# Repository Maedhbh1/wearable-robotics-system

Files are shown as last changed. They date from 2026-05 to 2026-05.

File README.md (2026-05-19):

# The Case for Misandry: A Networked Wearable Robotic Ecosystem

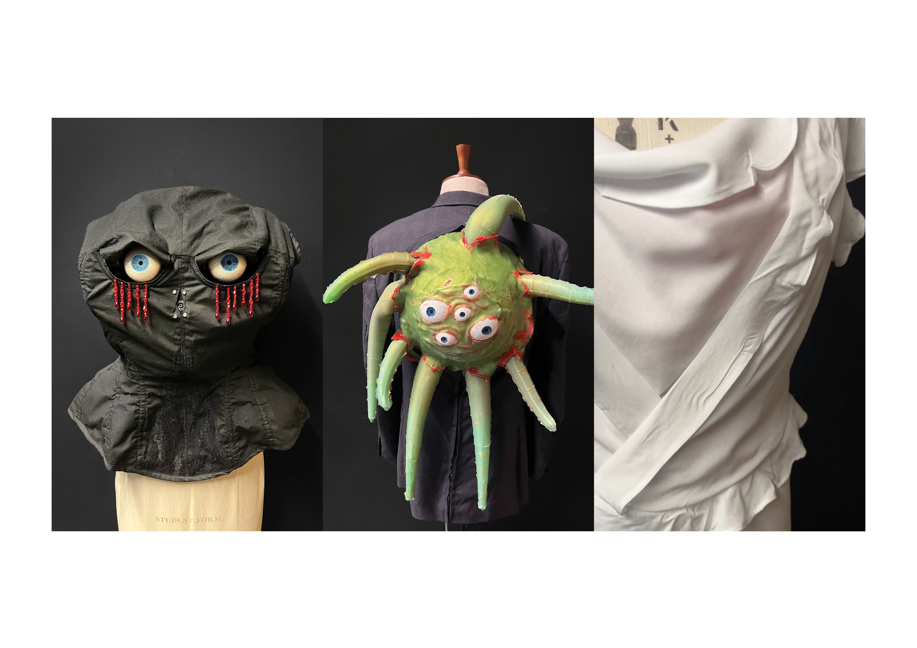
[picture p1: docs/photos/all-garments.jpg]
Three interconnected robotic garments displayed together


A networked system of three interconnected robotic garments that communicate in real time. Built as my MA Fashion Futures final project at London College of Fashion, UAL, and my first ever technical project.

Each garment operates as a node in a distributed system: a Raspberry Pi running a computer vision pipeline detects and tracks faces, triggering pneumatic soft robotic actuators across all three garments via ESP32 microcontrollers over a local Wi-Fi network. The result is a responsive, living ecosystem that reacts to the presence of a viewer.

▶ [Watch the system in action](https://youtube.com/shorts/KrzSbxakoQM)

---

## System Architecture

```
                  +----------------------------------+
                  |        Raspberry Pi              |
                  |   (Computer Vision / Master)     |
                  +----------------+-----------------+
                                   |
                  +----------------+----------------+
                  |        Local Wi-Fi Network        |
                  +--------+----------------+-------+
                           |                |
        HTTP GET /trigger  |                |  HTTP GET /trigger
        (192.168.1.103)    |                |  (192.168.1.200)
                           v                v
              +------------+----+      +----+------------+
              | Garment 2 ESP32 |      | Garment 3 ESP32 |
              |  The Tentacles  |      |    The Worms    |
              +------------+----+      +------------+----+
                           |                |
        Hardware Serial    |                |  Hardware Serial
             115200 baud   v                v  9600 baud
              +------------+----+      +----+------------+
              |  Arduino Mega   |      |  Arduino Mega   |
              | (Motor Control) |      |(Pneumatic Loop) |
              +-----------------+      +-----------------+
```

---

## The Garments

**Garment 1: The Eyes**
A Raspberry Pi runs a Python/OpenCV computer vision pipeline, tracking faces in real time and dispatching HTTP signals to the other garments. A second Pi drives a kiosk display showing a live web gallery built with Flask. On boot, the Pi emails its IP address automatically for remote access.

**Garment 2: The Tentacles**
An ESP32 receives the trigger signal and forwards it over hardware serial to an Arduino Mega, which drives motors and pneumatic pumps via a motorised pulley system and 3D-printed structures.

**Garment 3: The Worms**
An ESP32 hosts its own Wi-Fi access point and a simple web interface for manual start/stop control. It relays signals to an Arduino Mega running an 18-step non-blocking pneumatic state machine controlling six pumps and twelve valves.

---

## Tech Stack

**Hardware**
- Raspberry Pi (x2), Arduino Mega (x2), ESP32 (x2)
- Pneumatic soft robotic actuators (silicone-cast)
- Servo motors, peristaltic pumps, solenoid valves
- Custom PCBs (Garments 2 and 3)
- FDM 3D-printed structural components

**Software**
- Python, OpenCV, NumPy (computer vision pipeline)
- C++ via Arduino IDE (motor and pneumatic control)
- Flask, SQLite (web gallery and logging)
- HTML, CSS, JavaScript (gallery front end)
- I2C and Serial inter-chip communication

---

## Repository Structure

```
wearable-robotics-system/
├── garment-1-eyes/
│   ├── eyes-pi/               # Computer vision pipeline, web gallery, IP mailer
│   │   ├── eyes_control.py    # OpenCV face tracking and ESP32 signal dispatch
│   │   ├── web_gallery.py     # Flask web gallery and SQLite logging
│   │   └── send_ip.py         # Boot IP notification via email
│   ├── kiosk-pi/              # Second Pi running the kiosk display
│   │   ├── kiosk_start.sh     # Launches Chromium kiosk browser
│   │   └── kiosk_watchdog.sh  # Monitors connection and restarts if needed
│   └── hardware/              # Fusion 360 STL files (x14)
├── garment-2-tentacles/
│   ├── esp32-comms-G2/        # Receives HTTP trigger, relays over serial to Mega
│   │   └── esp32-comms-G2.ino
│   ├── mega-tentacle-control/ # Motor and pump control
│   │   └── mega-tentacle-control.ino
│   └── hardware/              # PCB designs, schematics
├── garment-3-worms/
│   ├── esp32-comms-G3/        # Wi-Fi AP, web interface, serial bridge
│   │   └── esp32-comms-G3.ino
│   ├── mega-worms-control/    # 18-step pneumatic state machine
│   │   └── mega-worms-control.ino
│   └── hardware/              # PCB designs, schematics
└── docs/
    └── photos/
```

---

## Hardware Communication

| Link | Device A | Device B | Pin | Baud Rate |
|---|---|---|---|---|
| Garment 2 | ESP32 TX2 (Pin 17) | Arduino Mega RX1 | Hardware Serial | 115200 |
| Garment 3 | ESP32 TX0 | Arduino Mega RX1 | Hardware Serial | 9600 |

---

## Setup

Before deploying, replace the following placeholders in the relevant files:

```python
# Raspberry Pi
ESP32_TENTACLE_IP = "192.168.1.YOUR_G2_IP"
ESP32_WORM_IP     = "192.168.1.YOUR_G3_IP"
```

```cpp
// ESP32 static IP config
IPAddress local_IP(192, 168, 1, YOUR_STATIC_IP);
IPAddress gateway(192, 168, 1, 1);
IPAddress subnet(255, 255, 255, 0);
```

Credentials to replace before pushing publicly:

- Wi-Fi SSID and password
- Gmail address and app password
- IFTTT webhook key (if used)
- File paths containing your username

**Raspberry Pi dependencies:**

```bash
sudo apt update && sudo apt install python3-pip chromium-browser -y
pip3 install -r requirements.txt
chmod +x garment-1-eyes/kiosk-pi/kiosk_start.sh
chmod +x garment-1-eyes/kiosk-pi/kiosk_watchdog.sh
```

**Arduino:** flash the relevant `.ino` files via Arduino IDE, selecting the correct board (ESP32 Dev Module or Arduino Mega 2560) and port for each.

---

## Credits

The eye mechanism 3D models in `garment-1-eyes/hardware/` are adapted from [EyeMech 1.0](https://willcogley.notion.site/EyeMech-1-0-983e6cad7059410d9cb958e8c1c5b700) by Will Cogley, licensed under [CC BY-NC-SA 4.0](http://creativecommons.org/licenses/by-nc-sa/4.0/). Modifications were made to fit the garment's structural requirements.
```

---

## The Garments

**Garment 1: The Eyes**
A Raspberry Pi runs a Python/OpenCV computer vision pipeline, tracking faces in real time and dispatching HTTP signals to the other garments. A second Pi drives a kiosk display showing a live web gallery built with Flask. On boot, the Pi emails its IP address automatically for remote access.

**Garment 2: The Tentacles**
An ESP32 receives the trigger signal and forwards it over hardware serial to an Arduino Mega, which drives motors and pneumatic pumps via a motorised pulley system and 3D-printed structures.

**Garment 3: The Worms**
An ESP32 hosts its own Wi-Fi access point and a simple web interface for manual start/stop control. It relays signals to an Arduino Mega running an 18-step non-blocking pneumatic state machine controlling six pumps and twelve valves.

---

## Tech Stack

**Hardware**
- Raspberry Pi (x2), Arduino Mega (x2), ESP32 (x2)
- Pneumatic soft robotic actuators (silicone-cast)
- Servo motors, peristaltic pumps, solenoid valves
- Custom PCBs (Garments 2 and 3)
- FDM 3D-printed structural components

**Software**
- Python, OpenCV, NumPy (computer vision pipeline)
- C++ via Arduino IDE (motor and pneumatic control)
- Flask, SQLite (web gallery and logging)
- HTML, CSS, JavaScript (gallery front end)
- I2C and Serial inter-chip communication

---

## Repository Structure

```
wearable-robotics-system/
├── garment-1-eyes/
│   ├── eyes-pi/               # Computer vision pipeline, web gallery, IP mailer
│   │   ├── eyes_control.py    # OpenCV face tracking and ESP32 signal dispatch
│   │   ├── web_gallery.py     # Flask web gallery and SQLite logging
│   │   └── send_ip.py         # Boot IP notification via email
│   ├── kiosk-pi/              # Second Pi running the kiosk display
│   │   ├── kiosk_start.sh     # Launches Chromium kiosk browser
│   │   └── kiosk_watchdog.sh  # Monitors connection and restarts if needed
│   └── hardware/              # Fusion 360 STL files (x14)
├── garment-2-tentacles/
│   ├── esp32-comms-G2/        # Receives HTTP trigger, relays over serial to Mega
│   │   └── esp32-comms-G2.ino
│   ├── mega-tentacle-control/ # Motor and pump control
│   │   └── mega-tentacle-control.ino
│   └── hardware/              # PCB designs, schematics
├── garment-3-worms/
│   ├── esp32-comms-G3/        # Wi-Fi AP, web interface, serial bridge
│   │   └── esp32-comms-G3.ino
│   ├── mega-worms-control/    # 18-step pneumatic state machine
│   │   └── mega-worms-control.ino
│   └── hardware/              # PCB designs, schematics
└── docs/
    └── photos/
```

---

## Hardware Communication

| Link | Device A | Device B | Pin | Baud Rate |
|---|---|---|---|---|
| Garment 2 | ESP32 TX2 (Pin 17) | Arduino Mega RX1 | Hardware Serial | 115200 |
| Garment 3 | ESP32 TX0 | Arduino Mega RX1 | Hardware Serial | 9600 |

---

## Setup

Before deploying, replace the following placeholders in the relevant files:

```python
# Raspberry Pi
ESP32_TENTACLE_IP = "192.168.1.YOUR_G2_IP"
ESP32_WORM_IP     = "192.168.1.YOUR_G3_IP"
```

```cpp
// ESP32 static IP config
IPAddress local_IP(192, 168, 1, YOUR_STATIC_IP);
IPAddress gateway(192, 168, 1, 1);
IPAddress subnet(255, 255, 255, 0);
```

Credentials to replace before pushing publicly:

- Wi-Fi SSID and password
- Gmail address and app password
- IFTTT webhook key (if used)
- File paths containing your username

**Raspberry Pi dependencies:**

```bash
sudo apt update && sudo apt install python3-pip chromium-browser -y
pip3 install -r requirements.txt
chmod +x garment-1-eyes/kiosk-pi/kiosk_start.sh
chmod +x garment-1-eyes/kiosk-pi/kiosk_watchdog.sh
```

**Arduino:** flash the relevant `.ino` files via Arduino IDE, selecting the correct board (ESP32 Dev Module or Arduino Mega 2560) and port for each.

---

## Credits

The eye mechanism 3D models in `garment-1-eyes/hardware/` are adapted from [EyeMech 1.0](https://willcogley.notion.site/EyeMech-1-0-983e6cad7059410d9cb958e8c1c5b700) by Will Cogley, licensed under [CC BY-NC-SA 4.0](http://creativecommons.org/licenses/by-nc-sa/4.0/). Modifications were made to fit the garment's structural requirements.

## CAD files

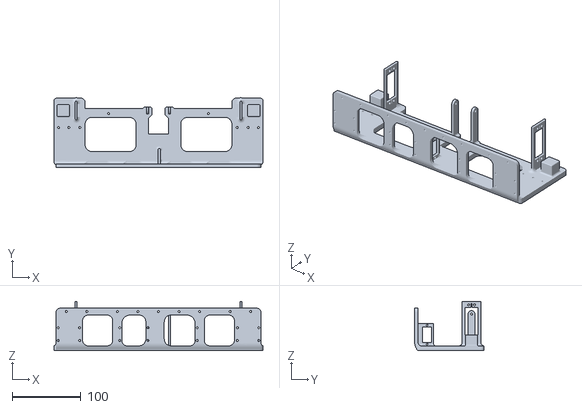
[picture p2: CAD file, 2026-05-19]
garment-1-eyes/hardware/Main Base F.stl
305.0 x 101.7 x 72.1

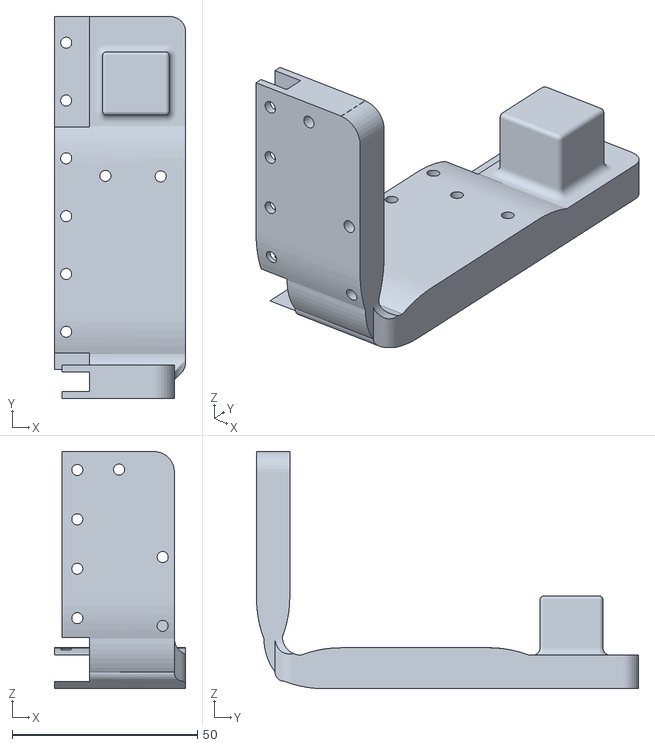
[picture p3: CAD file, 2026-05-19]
garment-1-eyes/hardware/Main Base L.stl
35.4 x 103.1 x 64.1

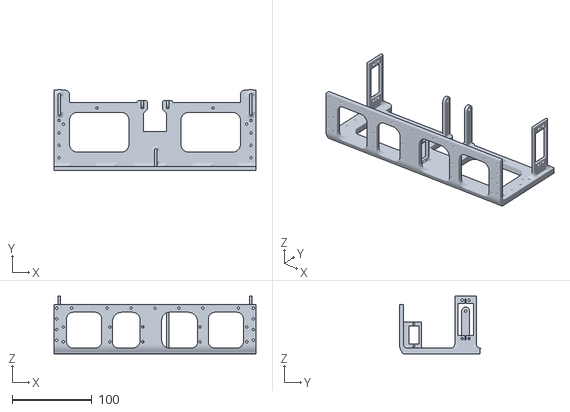
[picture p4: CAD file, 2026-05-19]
garment-1-eyes/hardware/Main Base C.stl
253.3 x 101.7 x 72.1

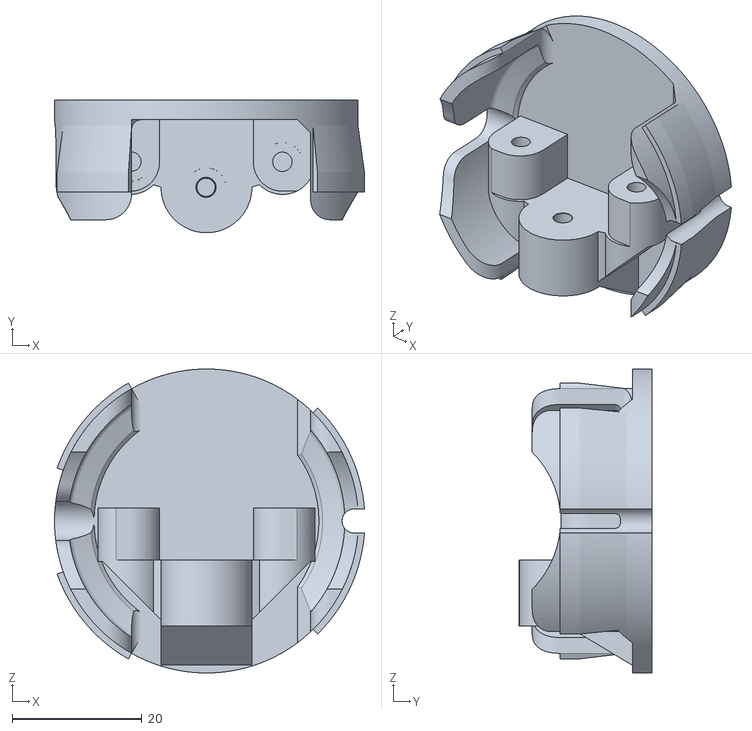
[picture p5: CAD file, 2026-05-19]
garment-1-eyes/hardware/Inner Eye.stl
47.7 x 20.4 x 46.8

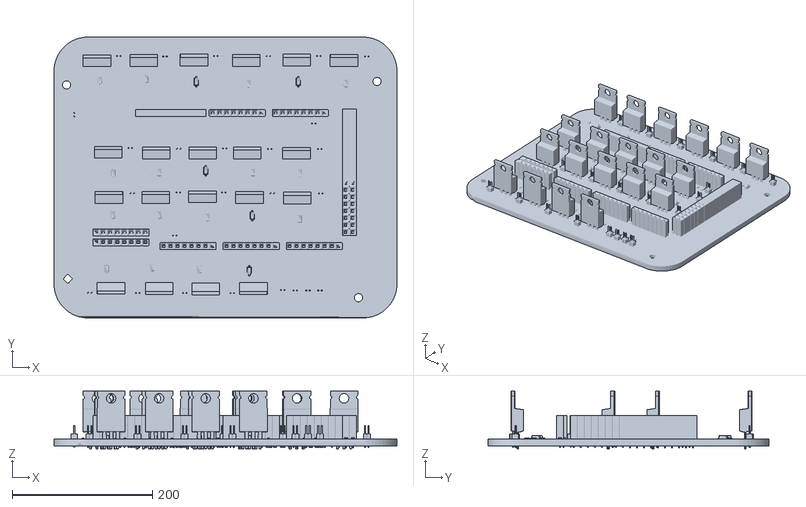
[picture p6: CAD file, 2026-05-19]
garment-2-tentacles/Hardware/OBJ_PCB_Monster.obj
489.3 x 400.7 x 82.1

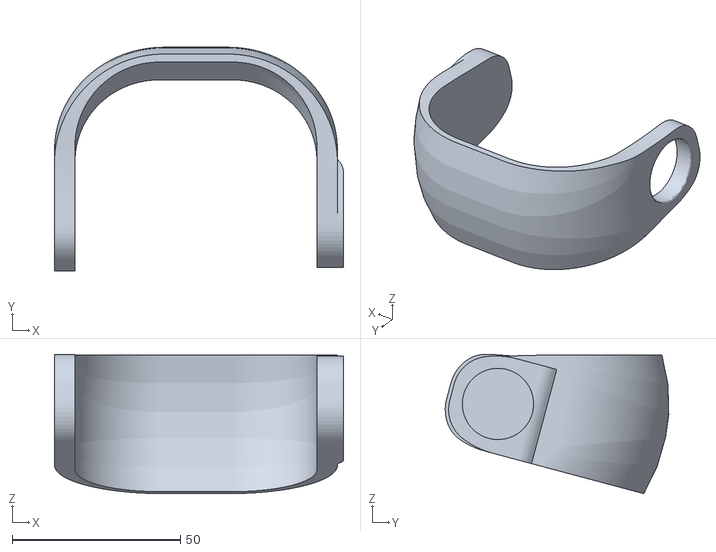
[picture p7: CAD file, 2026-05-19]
garment-1-eyes/hardware/Lid L.stl
86.0 x 66.5 x 41.5

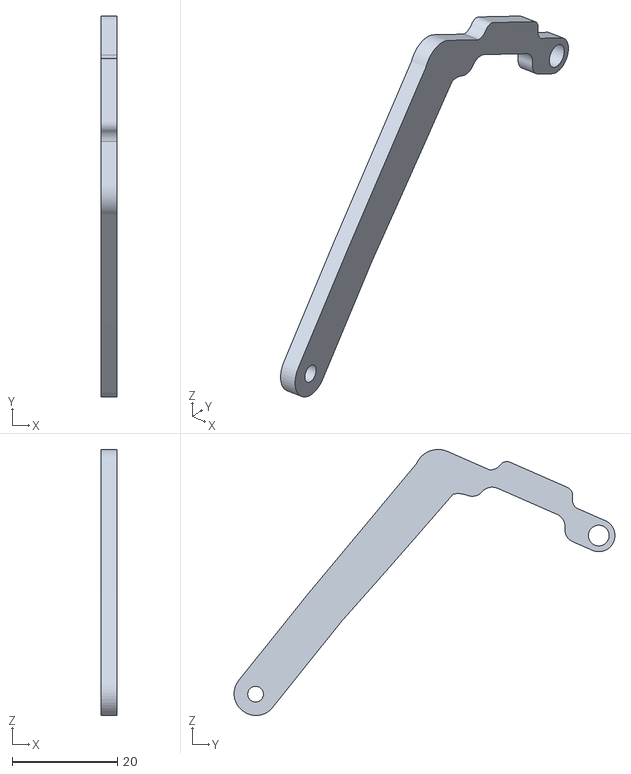
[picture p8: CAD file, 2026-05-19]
garment-1-eyes/hardware/Arm.stl
3.00 x 72.3 x 50.5

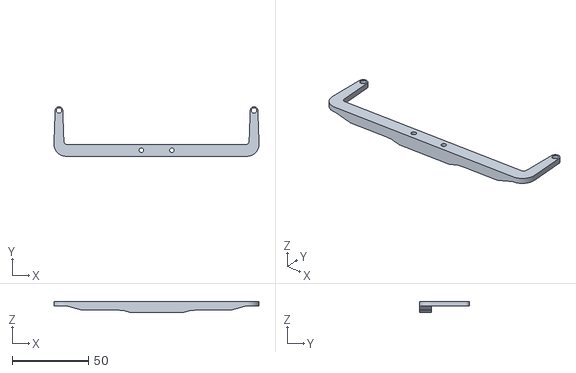
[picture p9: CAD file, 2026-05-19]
garment-1-eyes/hardware/Eye Holder.stl
134.5 x 32.5 x 7.53

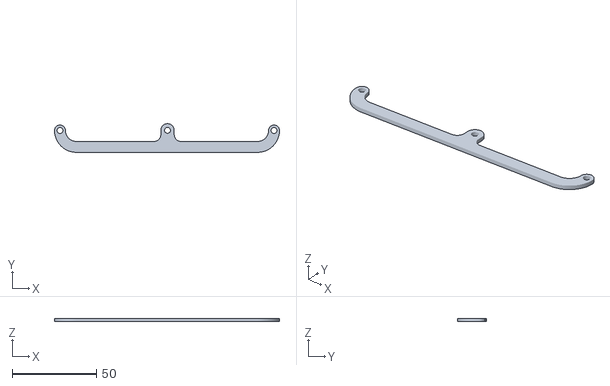
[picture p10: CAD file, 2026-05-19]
garment-1-eyes/hardware/Three-Point Connector.stl
133.8 x 17.1 x 2.00

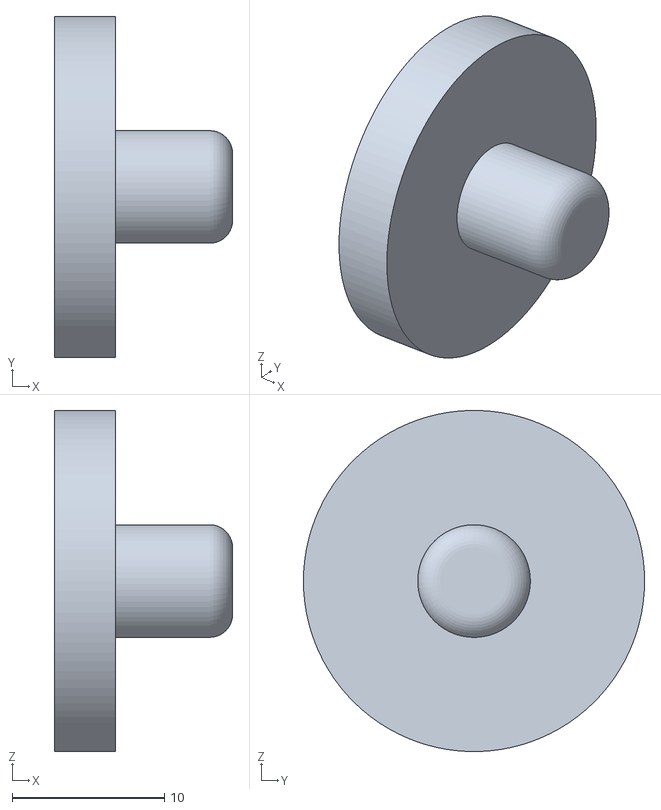
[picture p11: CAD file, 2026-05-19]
garment-1-eyes/hardware/inside bearing.stl
11.7 x 22.4 x 22.4

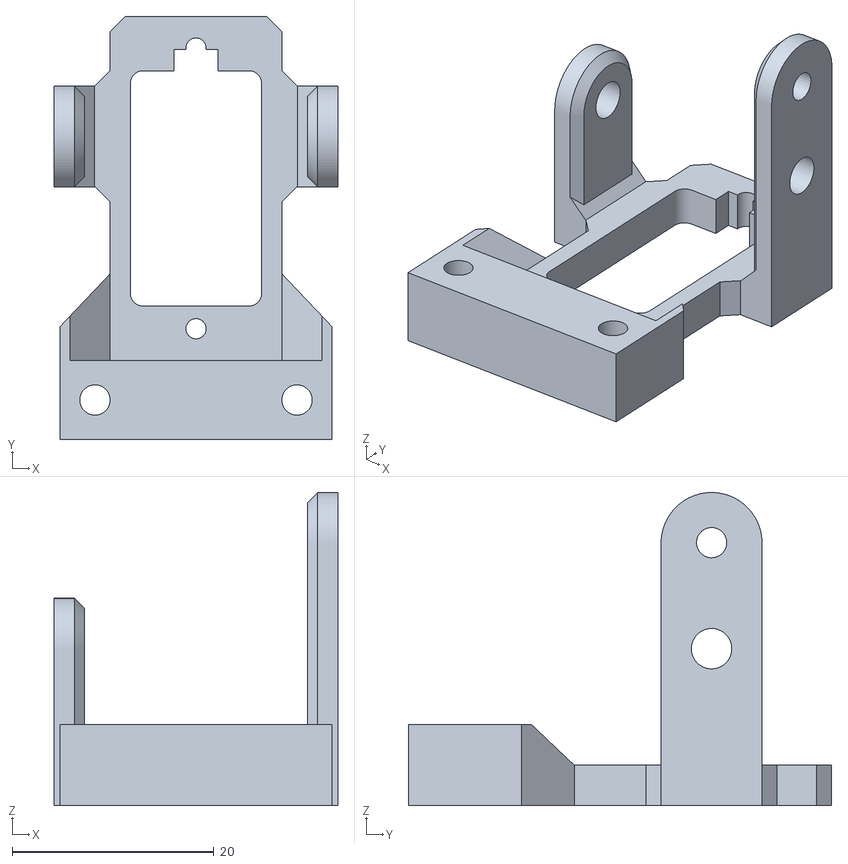
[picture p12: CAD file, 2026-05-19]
garment-1-eyes/hardware/Motor Holder.stl
28.1 x 41.9 x 31.0

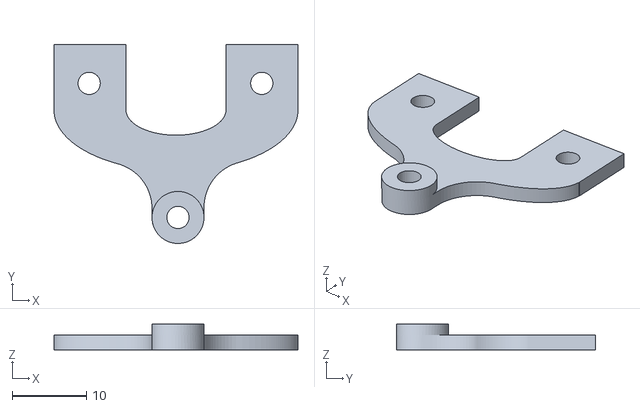
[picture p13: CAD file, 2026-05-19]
garment-1-eyes/hardware/Fork.stl
32.9 x 26.8 x 3.50

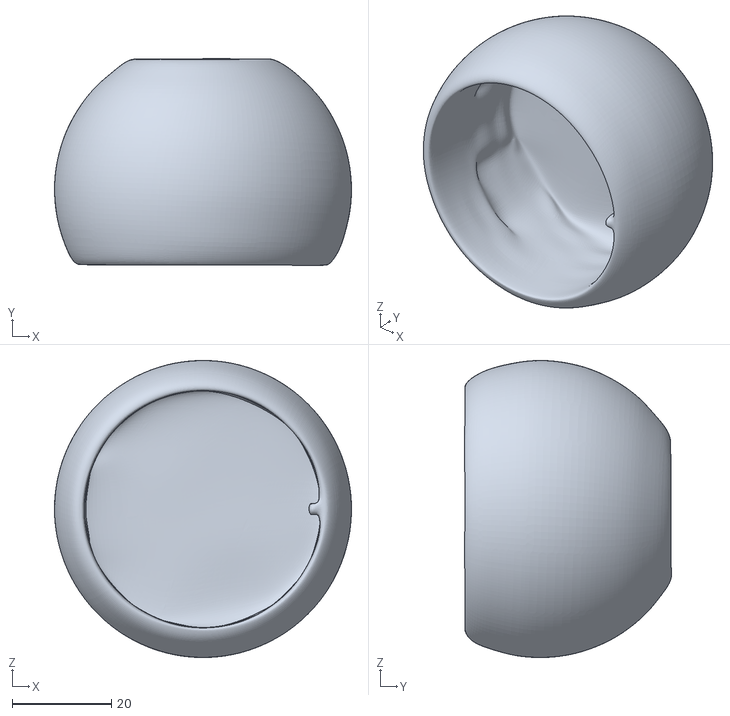
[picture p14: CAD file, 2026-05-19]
garment-1-eyes/hardware/Eye.stl
60.0 x 41.8 x 60.0

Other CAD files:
garment-1-eyes/hardware/Main Base R.stl
garment-1-eyes/hardware/Lid R.stl

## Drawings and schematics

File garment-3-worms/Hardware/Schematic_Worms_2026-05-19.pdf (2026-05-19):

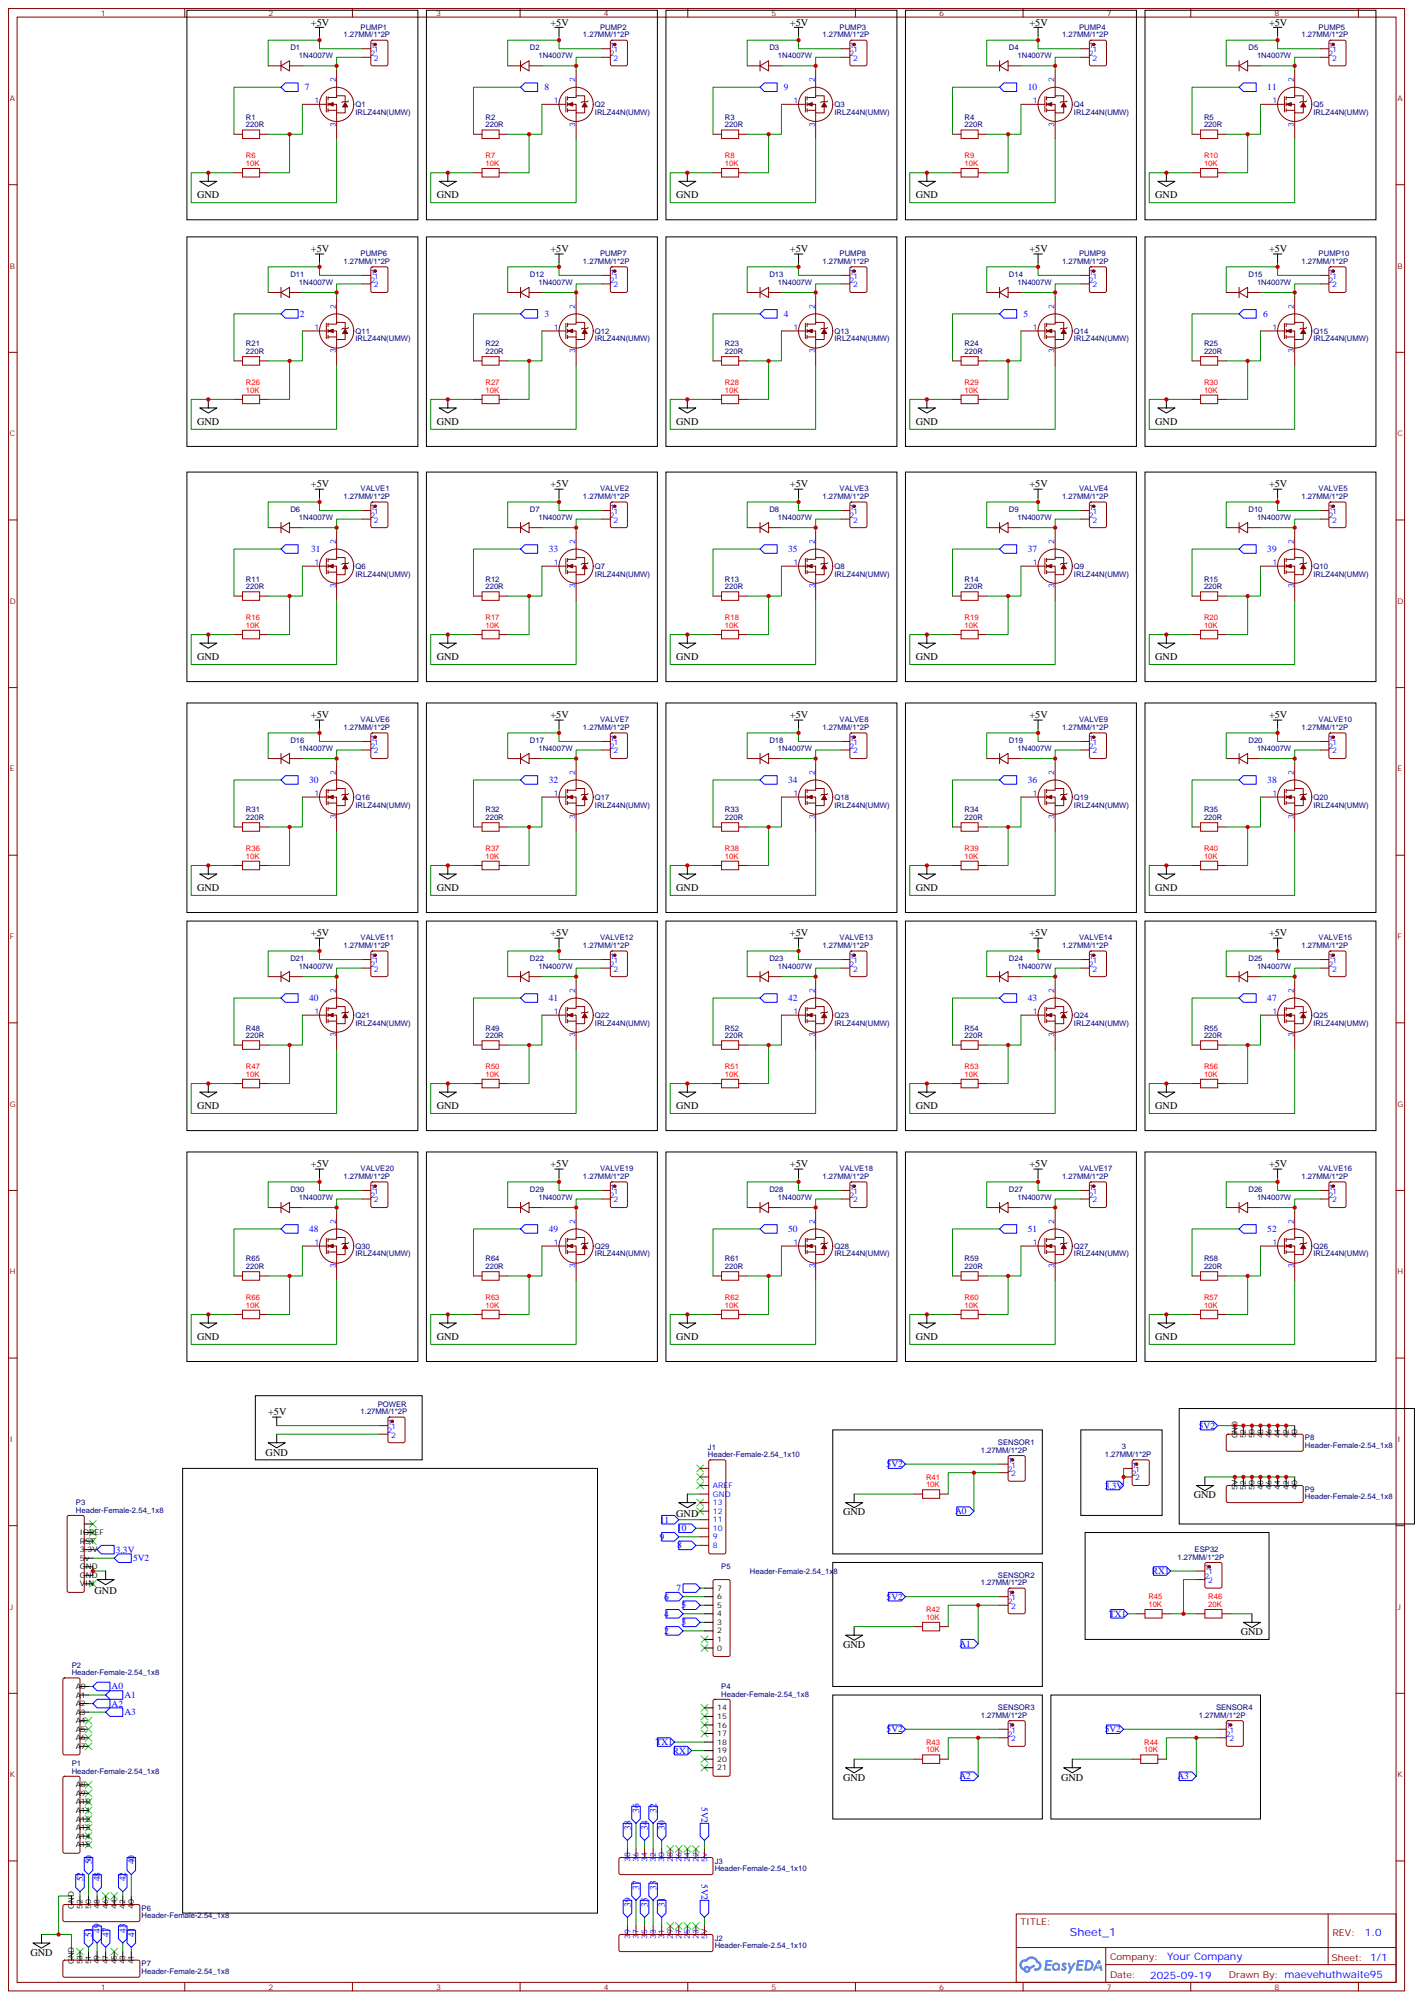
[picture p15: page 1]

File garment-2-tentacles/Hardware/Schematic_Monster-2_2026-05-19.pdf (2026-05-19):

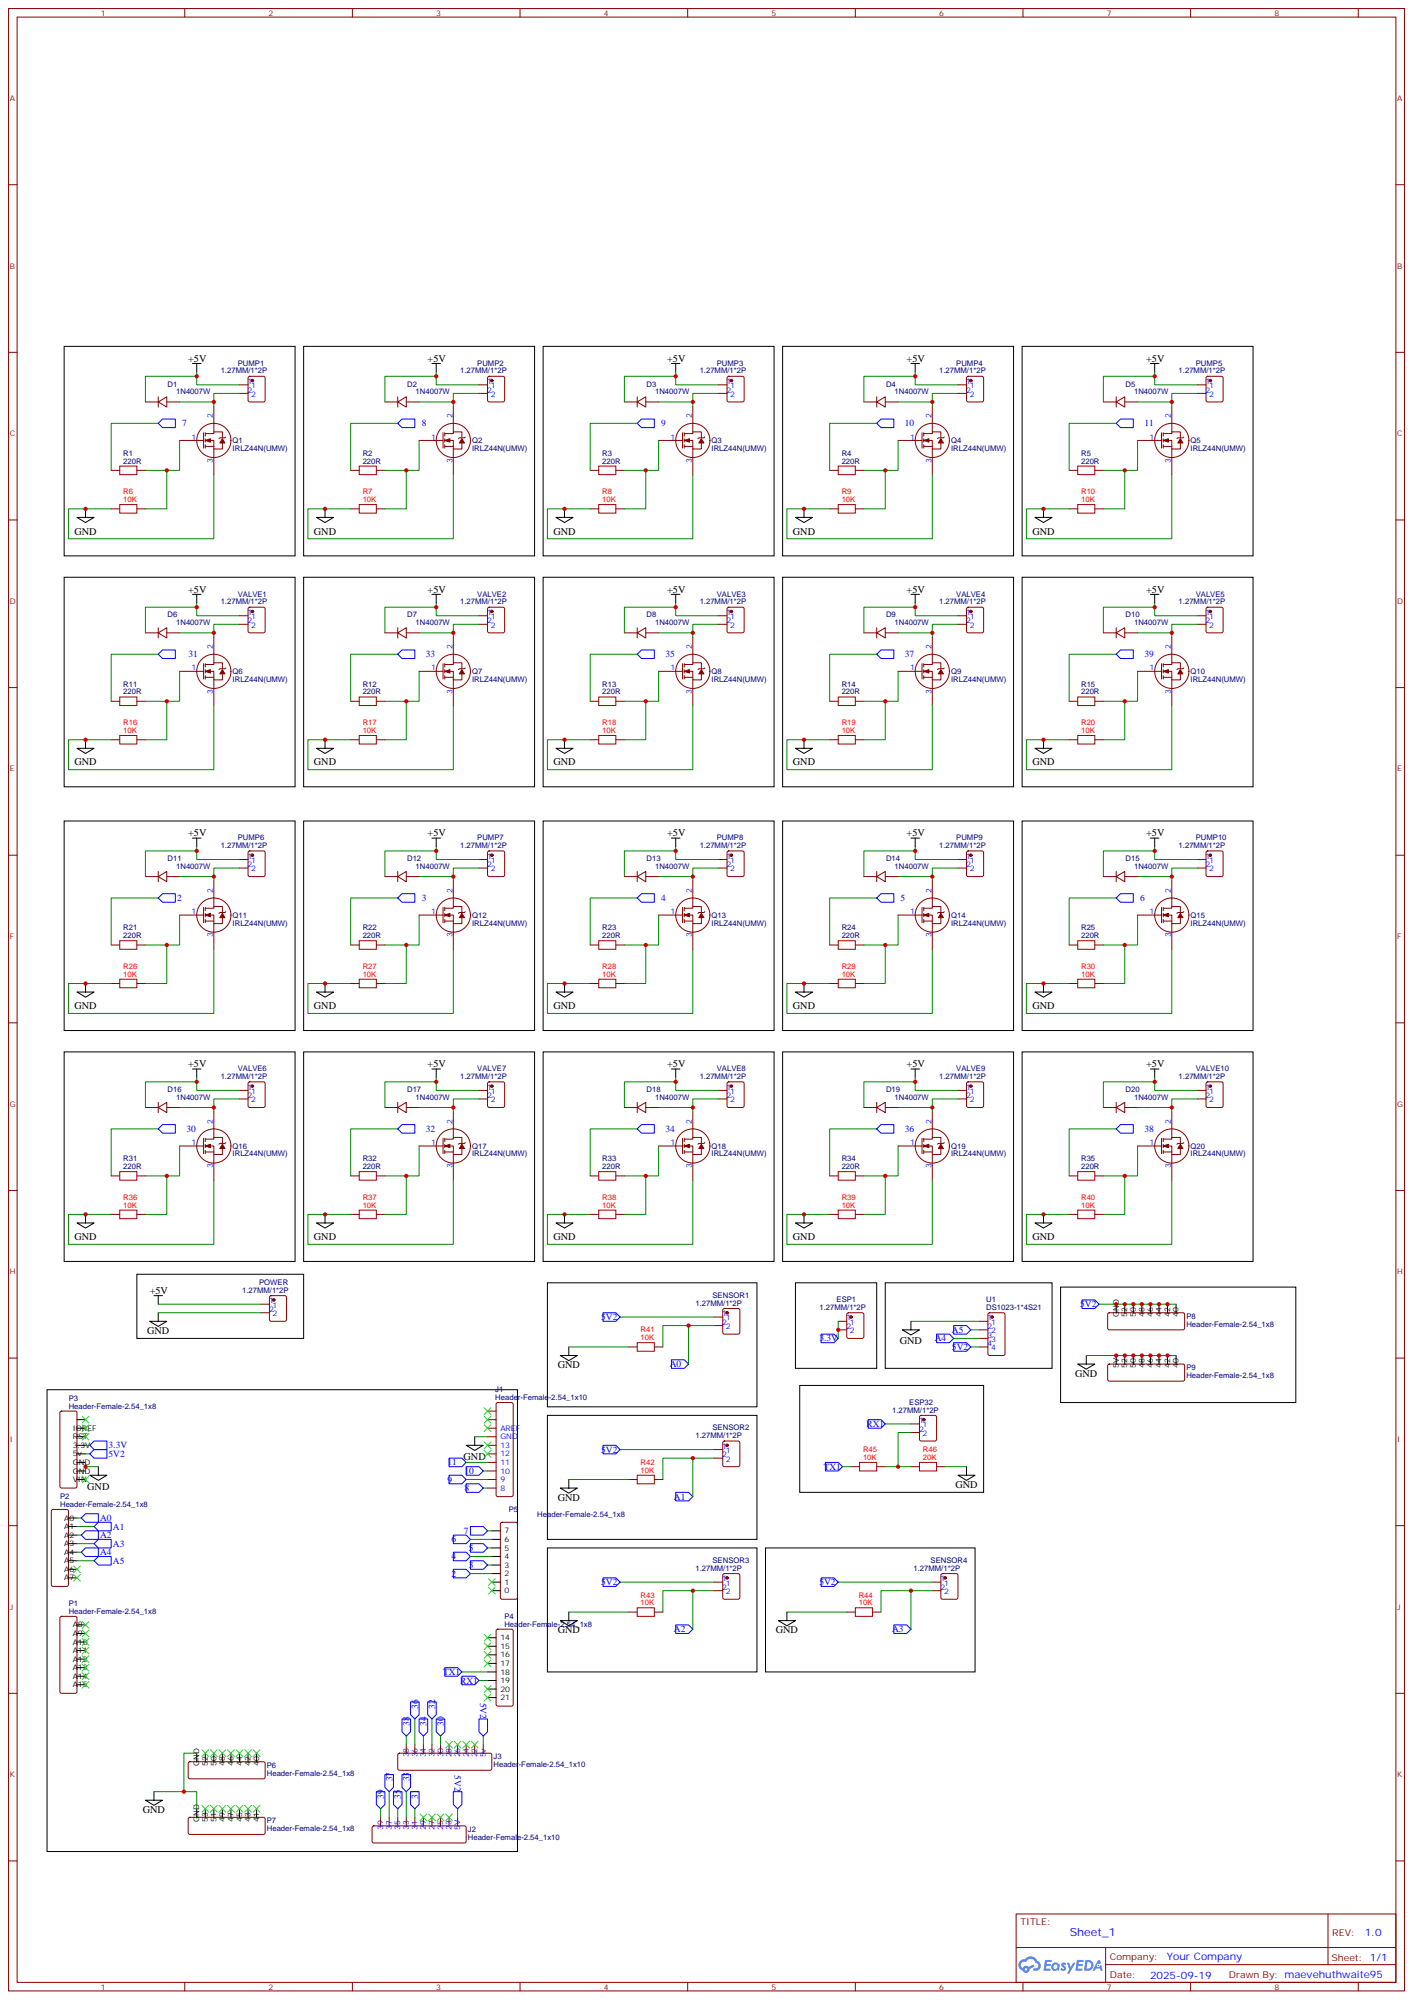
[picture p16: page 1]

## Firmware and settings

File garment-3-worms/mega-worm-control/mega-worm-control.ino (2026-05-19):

// Mega Serial Communication Setup:
// ESP32 TX connects to Arduino Mega RX1 (Digital Pin 19)
// Both boards MUST share a common ground (GND)

// --- Pump and Valve Pin Definitions ---
// Pumps (PWM pins)
const int PUMP3 = 9;
const int PUMP2 = 8; 
const int PUMP1 = 7; 
const int PUMP8 = 4; 
const int PUMP10 = 6;
const int PUMP9 = 5; 

// Valves (Digital pins)
const int VALVE12 = 41; // 3
const int VALVE13 = 42; 
const int VALVE3 = 35; // 2
const int VALVE11 = 40; 
const int VALVE1 = 31;  // 1
const int VALVE2 = 33;  
const int VALVE14 = 43;  // 8
const int VALVE15 = 47;
const int VALVE6 = 30;  //10
const int VALVE7 = 32;
const int VALVE9 = 36;  //9 
const int VALVE10 = 38;

// --- System Constants ---
const int POWER = 240; // PWM value for running pumps (255 is 100%)
const int STOP = 0;    // PWM value for stopping pumps

const char TRIGGER_CHAR = 'T'; // Starts the cycle
const char STOP_CHAR = 'S';    // Stops the cycle immediately

// --- State Machine Variables ---
enum CycleState { STATE_STOPPED, STATE_RUNNING, STATE_FINISHED };
CycleState currentState = STATE_STOPPED;
int currentStep = 0; // Tracks the current stage in the cycle (1, 2, 3...)
unsigned long previousMillis = 0; // Stores the last time an action was taken
unsigned long interval = 0;     // Duration for the current step

// --- FUNCTION PROTOTYPES ---
void resetPins();
void stopAllActivity();
void runPumpValveCycleNonBlocking();

// Function to turn off all pumps and close all valves (used for internal pauses/deflation)
void resetPins() {
  // Stop all pumps
  analogWrite(PUMP1, STOP);
  analogWrite(PUMP2, STOP);
  analogWrite(PUMP3, STOP);
  analogWrite(PUMP8, STOP);
  analogWrite(PUMP9, STOP);
  analogWrite(PUMP10, STOP);

  // Close all valves (set to LOW)
  digitalWrite(VALVE1, LOW);
  digitalWrite(VALVE2, LOW);
  digitalWrite(VALVE3, LOW);
  digitalWrite(VALVE6, LOW);
  digitalWrite(VALVE7, LOW);
  digitalWrite(VALVE9, LOW);
  digitalWrite(VALVE10, LOW);
  digitalWrite(VALVE11, LOW);
  digitalWrite(VALVE12, LOW);
  digitalWrite(VALVE13, LOW);
  digitalWrite(VALVE14, LOW);
  digitalWrite(VALVE15, LOW);
  Serial.println("All pins reset.");
}

// Function to immediately halt all activity (used for the STOP button)
void stopAllActivity() {
  resetPins();
  currentState = STATE_STOPPED; // Force the state to stopped
  currentStep = 0;              // Reset step counter
  Serial.println("!!! IMMEDIATE STOP COMMAND RECEIVED. ALL ACTIVITY HALTED. !!!");
}

// Function containing the entire pump/valve sequence using a non-blocking state machine
void runPumpValveCycleNonBlocking() {
  unsigned long currentMillis = millis();

  // If the system is stopped, do nothing here.
  if (currentState == STATE_STOPPED) {
    return;
  }
  
  // Check if it's time to transition to the next step
  if (currentMillis - previousMillis >= interval) {
    previousMillis = currentMillis; // Restart the timer
    currentStep++;                  // Move to the next step

    Serial.print("Executing Step: ");
    Serial.println(currentStep);

    // --- State Machine based on original cycle logic ---
    switch (currentStep) {
      case 1: // Start Cycle 1 - 1000ms
        interval = 1000;
        digitalWrite(VALVE12, HIGH); digitalWrite(VALVE13, LOW); analogWrite(PUMP3, POWER);
        digitalWrite(VALVE11, LOW); digitalWrite(VALVE3, LOW); analogWrite(PUMP2, STOP);
        digitalWrite(VALVE1, HIGH);  digitalWrite(VALVE2, LOW); analogWrite(PUMP1, POWER);
        digitalWrite(VALVE14, LOW); digitalWrite(VALVE15, LOW); analogWrite(PUMP8, STOP);
        digitalWrite(VALVE6, HIGH);  digitalWrite(VALVE7, LOW); analogWrite(PUMP10, POWER);
        digitalWrite(VALVE9, HIGH);  digitalWrite(VALVE10, LOW); analogWrite(PUMP9, POWER);
        break;

      case 2: // Hold Cycle 1 - 1000ms
        interval = 1000;
        digitalWrite(VALVE12, HIGH); digitalWrite(VALVE13, HIGH); analogWrite(PUMP3, STOP);
        digitalWrite(VALVE11, HIGH); digitalWrite(VALVE3, HIGH); analogWrite(PUMP2, STOP);
        digitalWrite(VALVE1, HIGH);  digitalWrite(VALVE2, HIGH); analogWrite(PUMP1, STOP);
        digitalWrite(VALVE14, HIGH); digitalWrite(VALVE15, HIGH); analogWrite(PUMP8, STOP);
        digitalWrite(VALVE6, HIGH);  digitalWrite(VALVE7, HIGH); analogWrite(PUMP10, STOP);
        digitalWrite(VALVE9, HIGH);  digitalWrite(VALVE10, HIGH); analogWrite(PUMP9, STOP);
        break;

      case 3: // Reverse Cycle 1 - 1000ms
        interval = 1000;
        digitalWrite(VALVE12, LOW);  digitalWrite(VALVE13, HIGH); analogWrite(PUMP3, POWER);
        digitalWrite(VALVE11, LOW);  digitalWrite(VALVE3, HIGH); analogWrite(PUMP2, POWER);
        digitalWrite(VALVE1, LOW);   digitalWrite(VALVE2, HIGH); analogWrite(PUMP1, POWER);
        digitalWrite(VALVE14, LOW);  digitalWrite(VALVE15, LOW); analogWrite(PUMP8, STOP);
        digitalWrite(VALVE6, LOW);   digitalWrite(VALVE7, HIGH); analogWrite(PUMP10, POWER);
        digitalWrite(VALVE9, LOW);   digitalWrite(VALVE10, HIGH); analogWrite(PUMP9, POWER);
        break;

      case 4: // Deflate (Reset Pins) - 1000ms
        interval = 600;
        resetPins();
        break;
      
      case 5: // Start Cycle 2 - 900ms
        interval = 1000;
        digitalWrite(VALVE12, HIGH); digitalWrite(VALVE13, LOW); analogWrite(PUMP3, POWER);
        digitalWrite(VALVE11, LOW);  digitalWrite(VALVE3, LOW); analogWrite(PUMP2, STOP);
        digitalWrite(VALVE1, HIGH);  digitalWrite(VALVE2, LOW); analogWrite(PUMP1, POWER);
        digitalWrite(VALVE14, LOW);  digitalWrite(VALVE15, LOW); analogWrite(PUMP8, STOP);
        digitalWrite(VALVE6, HIGH);  digitalWrite(VALVE7, LOW); analogWrite(PUMP10, POWER);
        digitalWrite(VALVE9, HIGH);  digitalWrite(VALVE10, LOW); analogWrite(PUMP9, POWER);
        break;

      case 6: // Hold Cycle 2 - 500ms
        interval = 500;
        digitalWrite(VALVE12, HIGH); digitalWrite(VALVE13, HIGH); analogWrite(PUMP3, STOP);
        digitalWrite(VALVE11, HIGH); digitalWrite(VALVE3, HIGH); analogWrite(PUMP2, STOP);
        digitalWrite(VALVE1, HIGH);  digitalWrite(VALVE2, HIGH); analogWrite(PUMP1, STOP);
        digitalWrite(VALVE14, LOW); digitalWrite(VALVE15, LOW); analogWrite(PUMP8, STOP);
        digitalWrite(VALVE6, HIGH);  digitalWrite(VALVE7, HIGH); analogWrite(PUMP10, STOP);
        digitalWrite(VALVE9, HIGH);  digitalWrite(VALVE10, HIGH); analogWrite(PUMP9, STOP);
        break;

      case 7: // Deflate (Reset Pins) - 900ms
        interval = 600;
        resetPins();
        break;

      case 8: // Reverse Cycle 2 - 800ms
        interval = 1000;
        digitalWrite(VALVE12, LOW);  digitalWrite(VALVE13, HIGH); analogWrite(PUMP3, STOP);
        digitalWrite(VALVE11, LOW); digitalWrite(VALVE3, LOW); analogWrite(PUMP2, STOP);
        digitalWrite(VALVE1, LOW);   digitalWrite(VALVE2, HIGH); analogWrite(PUMP1, POWER);
        digitalWrite(VALVE14, LOW);  digitalWrite(VALVE15, LOW); analogWrite(PUMP8, STOP);
        digitalWrite(VALVE6, LOW);   digitalWrite(VALVE7, HIGH); analogWrite(PUMP10, POWER);
        digitalWrite(VALVE9, HIGH);  digitalWrite(VALVE10, LOW); analogWrite(PUMP9, POWER);
        break;

      case 9: // Deflate (Reset Pins) - 800ms
        interval = 600;
        resetPins();
        break;

      case 10: // Start Cycle 3 - 400ms
        interval = 1000;
        digitalWrite(VALVE12, HIGH); digitalWrite(VALVE13, LOW); analogWrite(PUMP3, POWER);
        digitalWrite(VALVE11, LOW);  digitalWrite(VALVE3, HIGH); analogWrite(PUMP2, POWER);
        digitalWrite(VALVE1, HIGH);  digitalWrite(VALVE2, LOW); analogWrite(PUMP1, POWER);
        digitalWrite(VALVE14, LOW); digitalWrite(VALVE15, LOW); analogWrite(PUMP8, LOW);
        digitalWrite(VALVE6, HIGH);  digitalWrite(VALVE7, LOW); analogWrite(PUMP10, POWER);
        digitalWrite(VALVE9, LOW);   digitalWrite(VALVE10, HIGH); analogWrite(PUMP9, POWER);
        break;

      case 11: // Deflate (Reset Pins) - 900ms
        interval = 600;
        resetPins();
        break;

      case 12: // Reverse Cycle 3 (Part 1) - 1000ms
        interval = 1000;
        digitalWrite(VALVE12, LOW);  digitalWrite(VALVE13, LOW); analogWrite(PUMP3, STOP);
        digitalWrite(VALVE11, LOW); digitalWrite(VALVE3, LOW); analogWrite(PUMP2, STOP);
        digitalWrite(VALVE1, LOW);   digitalWrite(VALVE2, HIGH); analogWrite(PUMP1, POWER);
        digitalWrite(VALVE14, LOW);  digitalWrite(VALVE15, LOW); analogWrite(PUMP8, STOP);
        digitalWrite(VALVE6, LOW);   digitalWrite(VALVE7, HIGH); analogWrite(PUMP10, POWER);
        digitalWrite(VALVE9, HIGH);  digitalWrite(VALVE10, LOW); analogWrite(PUMP9, POWER);
        break;

      case 13: // Deflate (Reset Pins) - 800ms
        interval = 600;
        resetPins();
        break;

      case 14: // Start Cycle 3 (Part 2) - 1000ms
        interval = 1000;
        digitalWrite(VALVE12, HIGH); digitalWrite(VALVE13, LOW); analogWrite(PUMP3, POWER);
        digitalWrite(VALVE11, LOW); digitalWrite(VALVE3, HIGH); analogWrite(PUMP2, POWER);
        digitalWrite(VALVE1, HIGH);  digitalWrite(VALVE2, LOW); analogWrite(PUMP1, POWER);
        digitalWrite(VALVE14, LOW); digitalWrite(VALVE15, LOW); analogWrite(PUMP8, STOP);
        digitalWrite(VALVE6, HIGH);  digitalWrite(VALVE7, LOW); analogWrite(PUMP10, POWER);
        digitalWrite(VALVE9, HIGH);  digitalWrite(VALVE10, LOW); analogWrite(PUMP9, POWER);
        break;

      case 15: // Hold Cycle 3 - 1000ms
        interval = 1000;
        digitalWrite(VALVE12, HIGH); digitalWrite(VALVE13, HIGH); analogWrite(PUMP3, STOP);
        digitalWrite(VALVE11, HIGH); digitalWrite(VALVE3, HIGH); analogWrite(PUMP2, STOP);
        digitalWrite(VALVE1, HIGH);  digitalWrite(VALVE2, HIGH); analogWrite(PUMP1, STOP);
        digitalWrite(VALVE14, LOW); digitalWrite(VALVE15, LOW); analogWrite(PUMP8, STOP);
        digitalWrite(VALVE6, HIGH);  digitalWrite(VALVE7, HIGH); analogWrite(PUMP10, STOP);
        digitalWrite(VALVE9, HIGH);  digitalWrite(VALVE10, HIGH); analogWrite(PUMP9, STOP);
        break;

      case 16: // Reverse Cycle 3 (Part 3) - 1000ms
        interval = 1000;
        digitalWrite(VALVE12, LOW);  digitalWrite(VALVE13, HIGH); analogWrite(PUMP3, POWER);
        digitalWrite(VALVE11, LOW);  digitalWrite(VALVE3, HIGH); analogWrite(PUMP2, POWER);
        digitalWrite(VALVE1, LOW);   digitalWrite(VALVE2, HIGH); analogWrite(PUMP1, POWER);
        digitalWrite(VALVE14, LOW);  digitalWrite(VALVE15, LOW); analogWrite(PUMP8, STOP);
        digitalWrite(VALVE6, LOW);   digitalWrite(VALVE7, HIGH); analogWrite(PUMP10, POWER);
        digitalWrite(VALVE9, LOW);   digitalWrite(VALVE10, HIGH); analogWrite(PUMP9, POWER);
        break;

      case 17: // Final Deflate (Reset Pins) - 2000ms
        interval = 1000;
        resetPins();
        break;
      
      case 18: // Final Delay (Reset Pins) - 2000ms
        interval = 1000;
        resetPins();
        break;

      default:
        // Cycle completed all 18 steps, reset the counter to loop back to Step 1
        currentStep = 0; // Next iteration will be 1
        Serial.println("Cycle finished. Looping back to Step 1.");
        break;
    }
  }
}

void setup() {
  // Use Serial for debugging/monitor and Serial1 for communication with ESP32
  Serial.begin(9600);
  Serial1.begin(9600); // Initialize Serial1 for ESP32 communication

  // Pin Initialization (omitted for brevity, as it's the same as previous versions)

  pinMode(PUMP1, OUTPUT); pinMode(PUMP2, OUTPUT); pinMode(PUMP3, OUTPUT);
  pinMode(PUMP8, OUTPUT); pinMode(PUMP9, OUTPUT); pinMode(PUMP10, OUTPUT);

  pinMode(VALVE1, OUTPUT); pinMode(VALVE2, OUTPUT); pinMode(VALVE3, OUTPUT);
  pinMode(VALVE6, OUTPUT); pinMode(VALVE7, OUTPUT); pinMode(VALVE9, OUTPUT);
  pinMode(VALVE10, OUTPUT); pinMode(VALVE11, OUTPUT); pinMode(VALVE12, OUTPUT);
  pinMode(VALVE13, OUTPUT); pinMode(VALVE14, OUTPUT); pinMode(VALVE15, OUTPUT);

  // Initial State (STOP pumps, LOW valves)
  stopAllActivity(); 

  delay(1000); 
  Serial.println("Arduino Ready. Waiting for ESP32 trigger on Serial1...");
}

void loop() {
  // 1. Check for incoming serial commands from ESP32 first (High Priority)
  if (Serial1.available()) {
    char data = Serial1.read();
    
    if (data == TRIGGER_CHAR && currentState != STATE_RUNNING) {
      Serial.println("Trigger received, starting cycle...");
      currentState = STATE_RUNNING;
      currentStep = 0; // Will become 1 immediately after the loop runs
      previousMillis = millis(); 
    } else if (data == STOP_CHAR) {
      // If STOP character is received, halt immediately and reset state variables
      stopAllActivity(); // This sets currentState = STATE_STOPPED
    }
  }
  
  // 2. Run the non-blocking cycle logic if we are in the RUNNING state
  if (currentState == STATE_RUNNING) {
    runPumpValveCycleNonBlocking();
  }
}

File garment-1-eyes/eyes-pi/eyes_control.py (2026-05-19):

import cv2
from picamera2 import Picamera2
import time
import numpy as np
import board
import adafruit_pca9685
from adafruit_motor import servo
import threading
from datetime import datetime
import os
import glob
import requests


# Eye Control Parameters
X_SERVO_CHANNEL = 1
Y_SERVO_CHANNEL = 2
MIN_X_ANGLE = 50
MAX_X_ANGLE = 135
MIN_Y_ANGLE = 80
MAX_Y_ANGLE = 165
SERVO_MIN_PULSE = 500
SERVO_MAX_PULSE = 2500

# Lid Control Parameters
R_LID_SERVO_CHANNEL = 4
L_LID_SERVO_CHANNEL = 3

LRMAX_Y_ANGLE = 160   # Angle that physically OPENS the right lid
LRMIN_Y_ANGLE = 50  # Angle that physically CLOSES the right lid
LLMAX_Y_ANGLE = 60   # Angle that physically OPENS the left lid
LLMIN_Y_ANGLE = 170  # Angle that physically CLOSES the left lid

LID_CLOSE_DELAY = 5.0 # seconds

# Photo Deletion Parameters
PHOTO_DIR = "/home/admin/static/photos/"
MAX_PHOTOS = 50

# Camera to Eye Calibration 
CAM_NORM_X_MIN = 0.25
CAM_NORM_X_MAX = 0.75
CAM_NORM_Y_MIN = 0.25
CAM_NORM_Y_MAX = 0.75
INVERT_X_MAPPING = True
INVERT_Y_MAPPING = True

# AI Configuration 
MODEL_DIR = "/home/admin/face_detection_model/"
PROTOTXT_PATH = MODEL_DIR + "deploy.prototxt"
MODEL_PATH = MODEL_DIR + "res10_300x300_ssd_iter_140000.caffemodel"
CONFIDENCE_THRESHOLD = 0.5 # Default confidence
FRAME_WIDTH = 640
FRAME_HEIGHT = 480

# Threading, Smoothing, and Timing Parameters 
latest_target_servo_scaled_x = 0.5
latest_target_servo_scaled_y = 0.5
face_detected_in_thread = False
display_frame = np.zeros((FRAME_HEIGHT, FRAME_WIDTH, 3), dtype=np.uint8)
shared_data_lock = threading.Lock()
stop_threads_event = threading.Event()

SMOOTHING_FACTOR = 0.15
current_smoothed_servo_scaled_x = 0.5
current_smoothed_servo_scaled_y = 0.5

NO_FACE_TIMEOUT = 2.0
last_face_time_from_thread = time.time()
RETURN_TO_CENTER_ON_NO_FACE = True

SERVO_UPDATE_INTERVAL = 0.03
SERVO_MOVE_DELAY = 0.005

# Text Overlay Messages 
OVERLAY_MESSAGES = [
    "PERVERT",
    "CREEP",
    "WEIRDO",
    "PEEPING TOM",
    "SICKO",
    "INCEL"
]
current_message_index = 0 

# ESP32 Network Configeration 
# Garment 2 (Tentacle)
ESP32_TENTACLE_IP = "192.168.1.X"
TENTACLE_URL = f"http://{ESP32_TENTACLE_IP}/trigger"

# Garment 3 (Worm)
ESP32_WORM_IP = "192.168.1.Y"
WORM_URL = f"http://{ESP32_WORM_IP}/trigger"

# PCA9685 and Servo Initialization
def initialize_servos():
    i2c = board.I2C()
    pca = adafruit_pca9685.PCA9685(i2c)
    pca.frequency = 50

    x_servo = servo.Servo(pca.channels[X_SERVO_CHANNEL], min_pulse=SERVO_MIN_PULSE, max_pulse=SERVO_MAX_PULSE)
    y_servo = servo.Servo(pca.channels[Y_SERVO_CHANNEL], min_pulse=SERVO_MIN_PULSE, max_pulse=SERVO_MAX_PULSE)
    l_lid_servo = servo.Servo(pca.channels[L_LID_SERVO_CHANNEL], min_pulse=SERVO_MIN_PULSE, max_pulse=SERVO_MAX_PULSE)
    r_lid_servo = servo.Servo(pca.channels[R_LID_SERVO_CHANNEL], min_pulse=SERVO_MIN_PULSE, max_pulse=SERVO_MAX_PULSE)
    
    print(f"Servos initialized.")
    print(f"X on channel {X_SERVO_CHANNEL}, Y on channel {Y_SERVO_CHANNEL}, Left Lid on channel {L_LID_SERVO_CHANNEL}, Right Lid on channel {R_LID_SERVO_CHANNEL}")
    print(f"X-axis angle range: {MIN_X_ANGLE}-{MAX_X_ANGLE}")
    print(f"Y-axis angle range: {MIN_Y_ANGLE}-{MAX_Y_ANGLE}")
    print(f"Left Lid angle range: 'Closed'={LLMIN_Y_ANGLE}, 'Open'={LLMAX_Y_ANGLE}")
    print(f"Right Lid angle range: 'Closed'={LRMIN_Y_ANGLE}, 'Open'={LRMAX_Y_ANGLE}")
    print(f"Camera X-axis active normalized range: {CAM_NORM_X_MIN:.2f}-{CAM_NORM_X_MAX:.2f}")
    print(f"Camera Y-axis active normalized range: {CAM_NORM_Y_MIN:.2f}-{CAM_NORM_Y_MAX:.2f}")
    print(f"X-axis mapping inverted: {INVERT_X_MAPPING}, Y-axis mapping inverted: {INVERT_Y_MAPPING}")
    print(f"Smoothing Factor: {SMOOTHING_FACTOR}, Servo Update Interval: {SERVO_UPDATE_INTERVAL}s")
    print("Tracking logic: 1 face=track; 2-3 faces=track largest; >3 faces=cycle 1s per face.")
    return x_servo, y_servo, l_lid_servo, r_lid_servo, pca

# Eye Movement Functions
def move_eye_to_angle(x_servo, y_servo, x_angle, y_angle):
    clamped_x_angle = max(MIN_X_ANGLE, min(MAX_X_ANGLE, x_angle))
    clamped_y_angle = max(min(MIN_Y_ANGLE, MAX_Y_ANGLE), min(max(MIN_Y_ANGLE, MAX_Y_ANGLE), y_angle))
    try:
        if x_servo is not None: x_servo.angle = clamped_x_angle
        if y_servo is not None: y_servo.angle = clamped_y_angle
    except OSError as e: print(f"Servo I/O Error: {e}. Check connections.")
    except Exception as e: print(f"Error setting servo angle: {e}")
    if SERVO_MOVE_DELAY > 0: time.sleep(SERVO_MOVE_DELAY)

# Lid Movement Functions
def move_lids_to_angle(l_lid_servo, r_lid_servo, l_angle, r_angle):
    try:
        if l_lid_servo is not None:
            l_clamped_angle = max(min(LLMIN_Y_ANGLE, LLMAX_Y_ANGLE), min(max(LLMIN_Y_ANGLE, LLMAX_Y_ANGLE), l_angle))
            l_lid_servo.angle = l_clamped_angle
        if r_lid_servo is not None:
            r_clamped_angle = max(min(LRMIN_Y_ANGLE, LRMAX_Y_ANGLE), min(max(LRMIN_Y_ANGLE, LRMAX_Y_ANGLE), r_angle))
            r_lid_servo.angle = r_clamped_angle
    except OSError as e: print(f"Servo I/O Error: {e}. Check connections.")
    except Exception as e: print(f"Error setting servo angle: {e}")
    if SERVO_MOVE_DELAY > 0: time.sleep(SERVO_MOVE_DELAY)

# Photo Deletion Function
def manage_photos():
    if not os.path.exists(PHOTO_DIR):
        print(f"[INFO] Photo directory '{PHOTO_DIR}' does not exist. Skipping photo management.")
        return

    photos = glob.glob(os.path.join(PHOTO_DIR, "*.jpg"))
    photos.sort(key=os.path.getctime)
    
    num_photos = len(photos)
    if num_photos > MAX_PHOTOS:
        num_to_delete = num_photos - MAX_PHOTOS
        print(f"[INFO] Photo count ({num_photos}) exceeds max limit ({MAX_PHOTOS}). Deleting {num_to_delete} oldest photos.")
        for i in range(num_to_delete):
            try:
                os.remove(photos[i])
                print(f"🗑️  Deleted: {os.path.basename(photos[i])}")
            except OSError as e:
                print(f"[ERROR] Failed to delete file {photos[i]}: {e}")
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

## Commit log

2026-05-19 eyes upload
    [Arm.stl, Eye Holder.stl, Eye.stl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]
2026-05-19 tentacle upload
    [OBJ_PCB_Monster.obj]
